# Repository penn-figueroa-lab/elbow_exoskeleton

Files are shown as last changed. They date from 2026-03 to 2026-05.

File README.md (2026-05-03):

# 💪 Elbow Exoskeleton Project (On-Going*)






<div align="center">
<p float="left">
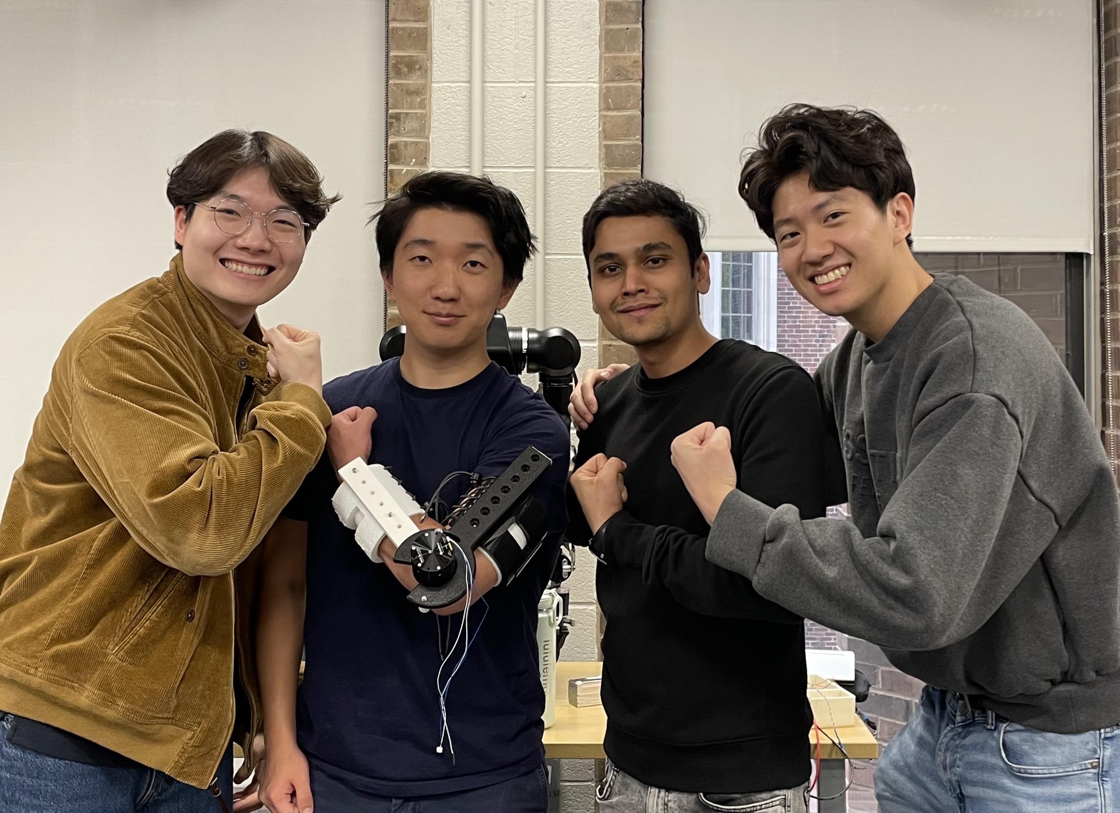
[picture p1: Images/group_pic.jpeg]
Elbow Exoskeleton
  
</p>
</div>

---

## 📋 Table of Contents

- [Overview](#-overview)
- [Key Features](#-key-features)
- [Repository Structure](#-repository-structure)
- [System Architecture](#-system-architecture)
- [Technical Approach](#-technical-approach)
  - [1. Hardware Design](#1-hardware-design)
    - [1.1 Left vs. Right Arm Versions](#11-left-vs-right-arm-versions)
    - [1.2 Structural Linkages](#12-structural-linkages)
    - [1.3 Orthotics](#13-orthotics)
    - [1.4 Safety Systems](#14-safety-systems)
    - [1.5 Snap-Fit Forearm Extension](#15-snap-fit-forearm-extension)
    - [1.6 Materials & Print Settings](#16-materials--print-settings)
    - [1.7 Bill of Materials](#17-bill-of-materials)
  - [2. Multi-Modal Sensor Fusion](#2-multi-modal-sensor-fusion)
  - [3. Comparative Controller Evaluation](#3-comparative-controller-evaluation)
- [CAD Files](#-cad-files)
- [STL Files & Printing Guide](#-stl-files--printing-guide)
- [Assembly Instructions](#-assembly-instructions)
- [Donning & Doffing](#-donning--doffing)
- [Performance Results](#-performance-results)
- [Acknowledgments](#-acknowledgments)

---

## 🎯 Overview

Upper limb exoskeletons for repetitive industrial tasks must adapt to time-varying human dynamics: fatigue, impedance changes, and overlapping kinematics. Single-modality sensing leads to state misclassification and suboptimal assistance. This project develops a sensor fusion framework integrating EMG, IMU, and MoCap to robustly estimate user state during repetitive lifting tasks. Through comparative controller evaluation and ablation studies, we quantify how multi-modal sensing improves adaptive control performance and enables more reliable, responsive assistance.

---

**Institution**: University of Pennsylvania  
**Exoskeleton**: 1-DOF elbow, 0–115° ROM, 1100 g total weight  
**Actuator**: Cubemars AK45-36 KV80 BLDC (15 Nm continuous, 24 Nm peak)  
**Sensing**: EMG + IMU + Motion Capture

---

## ✨ Key Features

### 🔧 Core Capabilities

- ✅ **Single-DOF Elbow Exoskeleton** — 0–115° range of motion, matching typical human elbow flexion/extension
- ✅ **Left & Right Arm Versions** — mirrored CAD designs accommodating both limbs
- ✅ **Cubemars AK45-36 BLDC Actuator** — 15 Nm output torque, back-driven for transparency
- ✅ **Snap-Fit Forearm Linkage** — two-piece print-in-place design compensating for ~8 mm elbow COR shift during actuation
- ✅ **Dual Safety Stops** — software joint-angle limit + hardware M6 screw/nut with TPU cover
- ✅ **Multi-Size Orthotics** — 3 forearm sizes (R35/40/45) and 3 upper arm sizes (R45/50/55 mm inner radius)
- ✅ **Structural Orthotic Inserts** — PLA inserts inside TPU orthotics to minimize torsional twist at linkage interfaces
- ✅ **EMG Sensor Slots** — integrated bicep and tricep sensor pockets in upper arm orthotic
- ✅ **Back-Mounted Power/Control Unit** — 650 g, wireless operation
- ✅ **Multi-Modal Sensor Fusion** — EMG + IMU + MoCap integrated state estimation
- ✅ **Fatigue Detection** — tracks time-varying muscle activation and joint impedance
- ✅ **Comparative Controller Study** — ablation analysis (EMG-only, IMU-only, fused)
- ✅ **Adaptive Assistance** — torque profiles adjust to detected user state

### 🎓 Advanced Techniques

- Kalman filtering for sensor fusion across asynchronous EMG/IMU/MoCap streams
- Fatigue index computation from EMG median frequency shift and RMS amplitude decay
- Impedance estimation from joint torque-angle phase portraits
- Overlapping kinematic disambiguation via multi-modal likelihood weighting

---

## 📁 Repository Structure

```
elbow_exoskeleton/
├── Images/                        # Photos and renders used in README
├── CAD/
│   ├── Elbow Exoskeleton - Left/  # SolidWorks files for the left arm assembly
│   │   ├── Elbow Exoskeleton - Left.sldasm
│   │   ├── Forearm linkage assembly.sldasm
│   │   ├── Forearm linkage base.sldprt
│   │   ├── Forearm linkage front.sldprt
│   │   ├── Forearm orthotic R45 - Left.sldprt
│   │   ├── Forearm orthotic structural insert.sldprt
│   │   ├── Mechanical stop cover.sldprt
│   │   ├── Upper arm linkage - Left.sldprt
│   │   ├── Upper arm orthotic R55 - Left.sldprt
│   │   ├── Upper arm orthotic structural insert.sldprt
│   │   ├── AK45-36-KV80 motor.sldprt
│   │   ├── ANR Muscle Sense Model M40 EMG sensor.sldprt
│   │   ├── 90592A016_Steel Hex Nut_M6.sldprt
│   │   ├── 92005A427_Steel Pan Head Phillips Screw_M6_18mm.sldprt
│   │   └── 92005A435_Steel Pan Head Phillips Screw_M6_30mm.sldprt
│   ├── Elbow Exoskeleton - Right/ # SolidWorks files for the right arm assembly
│   │   ├── Elbow Exoskeleton - Right.sldasm
│   │   ├── Forearm linkage assembly.sldasm
│   │   ├── Forearm linkage base.sldprt
│   │   ├── Forearm linkage front.sldprt
│   │   ├── Forearm orthotic R45 - Right.sldprt
│   │   ├── Forearm orthotic structural insert.sldprt
│   │   ├── Mechanical stop cover.sldprt
│   │   ├── Upper arm linkage - Right.sldprt
│   │   ├── Upper arm orthotic R55 - Right.sldprt
│   │   ├── Upper arm orthotic structural insert.sldprt
│   │   ├── AK45-36-KV80 motor.sldprt
│   │   ├── ANR Muscle Sense Model M40 EMG sensor.sldprt
│   │   ├── 90592A016_Steel Hex Nut_M6.sldprt
│   │   ├── 92005A427_Steel Pan Head Phillips Screw_M6_18mm.sldprt
│   │   └── 92005A435_Steel Pan Head Phillips Screw_M6_30mm.sldprt
│   └── STL files/                 # Print-ready STL files for all printed parts
│       ├── Forearm linkage assembly.stl
│       ├── Forearm orthotic R35/R40/R45 - Left/Right.stl  (6 files)
│       ├── Upper arm orthotic R45/R50/R55 - Left/Right.stl (6 files)
│       ├── Forearm orthotic structural insert.stl
│       ├── Upper arm orthotic structural insert.stl
│       ├── Upper arm linkage - Left/Right.stl
│       └── Mechanical stop cover.stl
├── Print Files/
│   ├── BambuStudio/               # .3mf Bambu Studio project files with pre-configured print settings
│   └── Print Orientation Guide/   # Screenshots showing recommended print orientations
└── README.md
```

> **Note on Left vs. Right folders:** Each assembly folder contains all parts needed to open and rebuild that assembly in SolidWorks — shared parts (forearm linkage, structural inserts, hardware) are duplicated across both folders for self-containment. The only parts that differ between folders are the upper arm linkage, upper arm orthotic, and forearm orthotic, which are mirrored versions of each other. Only **one orthotic size is included per assembly folder** (the example shown uses R45 forearm / R55 upper arm) — select the appropriate size for your subject from the full set in `CAD/STL files/`.

---

## 🏗️ System Architecture

```
┌─────────────────────────────────────────────────────────────────────┐
│              ELBOW EXOSKELETON CONTROL SYSTEM                       │
│                                                                     │
│   ┌──────────────────────────────────────────────────────────────┐  │
│   │                  SENSING LAYER                               │  │
│   │                                                              │  │
│   │   EMG Sensors (biceps, triceps)                              │  │
│   │     ├── Muscle activation intent                             │  │
│   │     └── Fatigue indicators (median freq, RMS)                │  │
│   │                      │                                       │  │
│   │   IMU (elbow joint)                                          │  │
│   │     ├── Joint angle, velocity, acceleration                  │  │
│   │     └── Motion phase detection                               │  │
│   │                      │                                       │  │
│   │   MoCap (ground truth)                                       │  │
│   │     └── High-precision kinematic validation                  │  │
│   └──────────────────────┬───────────────────────────────────────┘  │
│                          │                                          │
│                          ▼                                          │
│   ┌──────────────────────────────────────────────────────────────┐  │
│   │              SENSOR FUSION FRAMEWORK                         │  │
│   │                                                              │  │
│   │   Kalman Filter / Complementary Filter                       │  │
│   │     Input:  EMG(t), IMU(t), MoCap(t)                         │  │
│   │     Output: User state estimate                              │  │
│   │                                                              │  │
│   │   State variables:                                           │  │
│   │     - Joint angle θ, velocity θ̇                              │  │
│   │     - Muscle activation level (normalized EMG)               │  │
│   │     - Fatigue index (0 = fresh, 1 = exhausted)               │  │
│   │     - Estimated joint impedance                              │  │
│   └──────────────────────┬───────────────────────────────────────┘  │
│                          │  fused state estimate                    │
│                          ▼                                          │
│   ┌──────────────────────────────────────────────────────────────┐  │
│   │          COMPARATIVE CONTROLLER EVALUATION                   │  │
│   │                                                              │  │
│   │   Controller A: EMG-only (baseline)                          │  │
│   │   Controller B: IMU-only (baseline)                          │  │
│   │   Controller C: Fused EMG+IMU+MoCap (proposed)               │  │
│   │                                                              │  │
│   │   Metrics: Assistance timing accuracy, torque tracking,      │  │
│   │            false positive rate, fatigue adaptation           │  │
│   └──────────────────────┬───────────────────────────────────────┘  │
│                          │  torque command                          │
│                          ▼                                          │
│   ┌──────────────────────────────────────────────────────────────┐  │
│   │          ADAPTIVE CONTROLLER                                 │  │
│   │                                                              │  │
│   │   Torque profile selection based on:                         │  │
│   │     - Detected motion phase (rest / lift / lower)            │  │
│   │     - Fatigue level (scale assistance magnitude)             │  │
│   │     - Estimated impedance (adjust compliance)                │  │
│   └──────────────────────┬───────────────────────────────────────┘  │
│                          │                                          │
│                          ▼                                          │
│   ┌──────────────────────────────────────────────────────────────┐  │
│   │          CUBEMARS AK45-36 BLDC ACTUATOR                      │  │
│   │                                                              │  │
│   │   Input:   Torque setpoint (Nm)                              │  │
│   │   Output:  Elbow joint torque (15 Nm max continuous)         │  │
│   │   Control: Current loop on motor controller                  │  │
│   └──────────────────────────────────────────────────────────────┘  │
└─────────────────────────────────────────────────────────────────────┘
```

---

## 🔬 Technical Approach

<div align="center">
<p float="left">
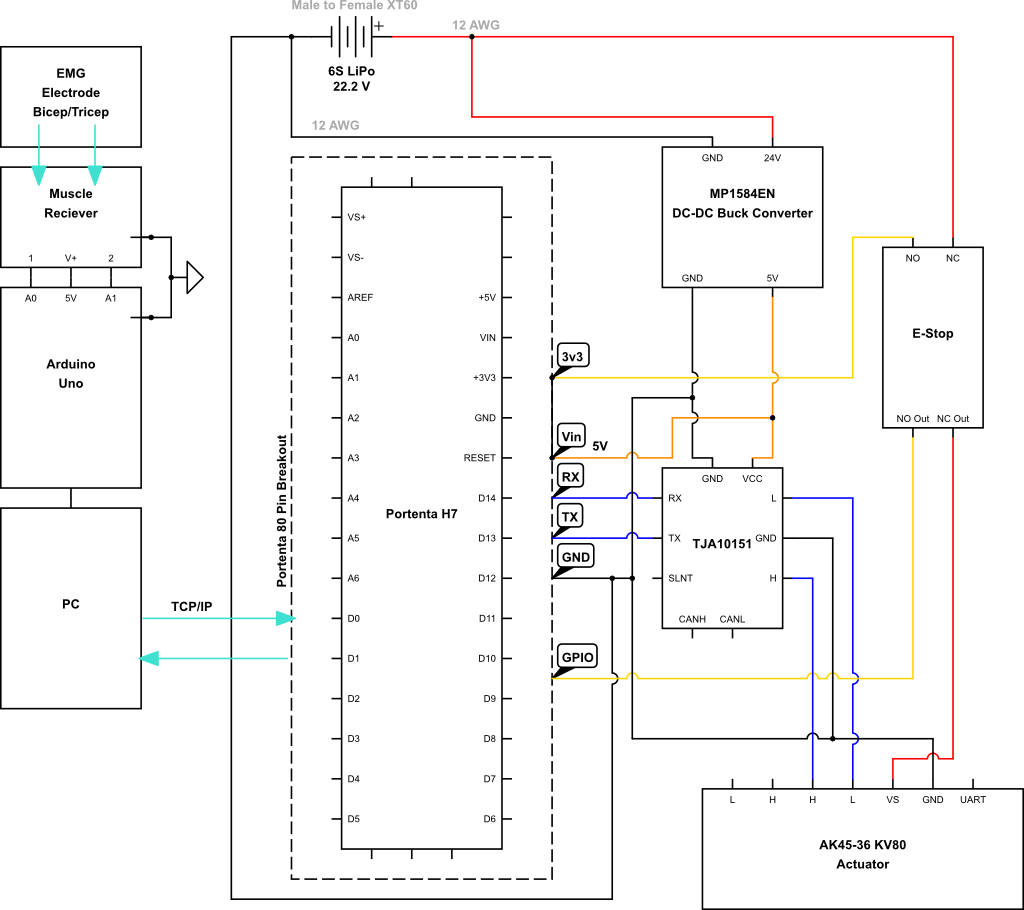
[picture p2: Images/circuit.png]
Electronics circuit
  
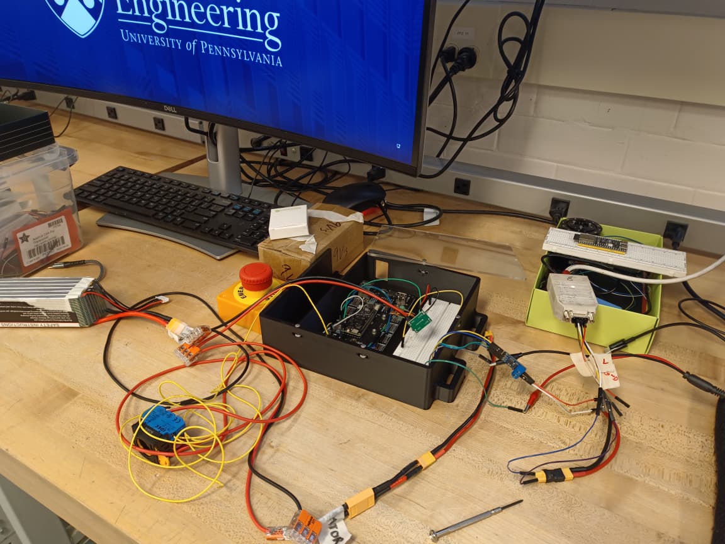
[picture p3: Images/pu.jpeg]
Power unit
  
</p>
</div>

### 1. Hardware Design

#### 1.1 Left vs. Right Arm Versions

The exoskeleton is available in two mirrored versions — **Left** and **Right** — to accommodate both arms. The motor is positioned at the elbow joint and the user operates with **palms facing upward** (supinated). Shoe laces run along the **top** of each orthotic, and the orthotics mount to their respective linkages from the side.

The **forearm linkage assembly is identical** across both versions. Only the following parts differ (mirrored CAD):

| Part | Left Version | Right Version |
|---|---|---|
| Upper arm linkage | ✅ | ✅ |
| Upper arm orthotic | ✅ | ✅ |
| Forearm orthotic | ✅ | ✅ |
| Forearm linkage | Shared | Shared |

<div align="center">
<p float="left">
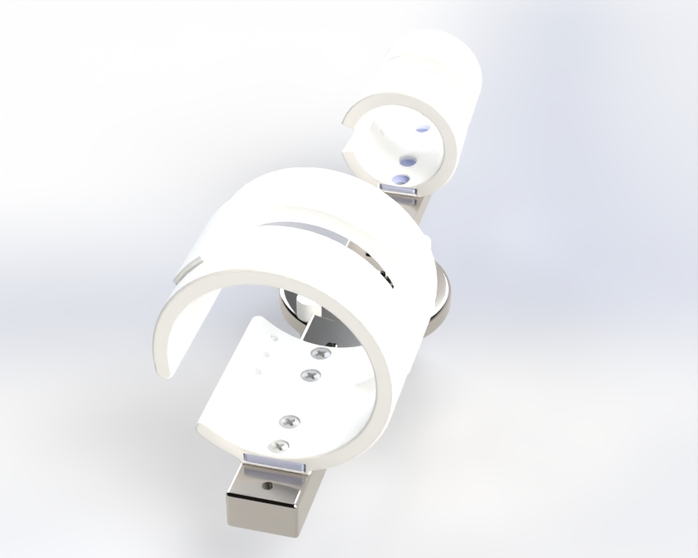
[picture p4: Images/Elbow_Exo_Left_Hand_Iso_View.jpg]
Left arm version
  
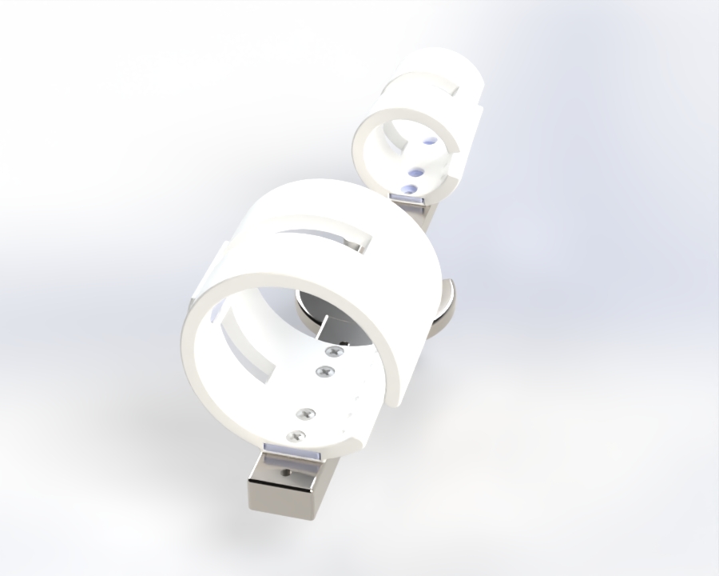
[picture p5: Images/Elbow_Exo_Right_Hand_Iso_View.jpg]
Right arm version
  
</p>
<em>Left (left) and Right (right) arm versions of the elbow exoskeleton assembly</em>
</div>

#### 1.2 Structural Linkages

<div align="center">
<p float="left">
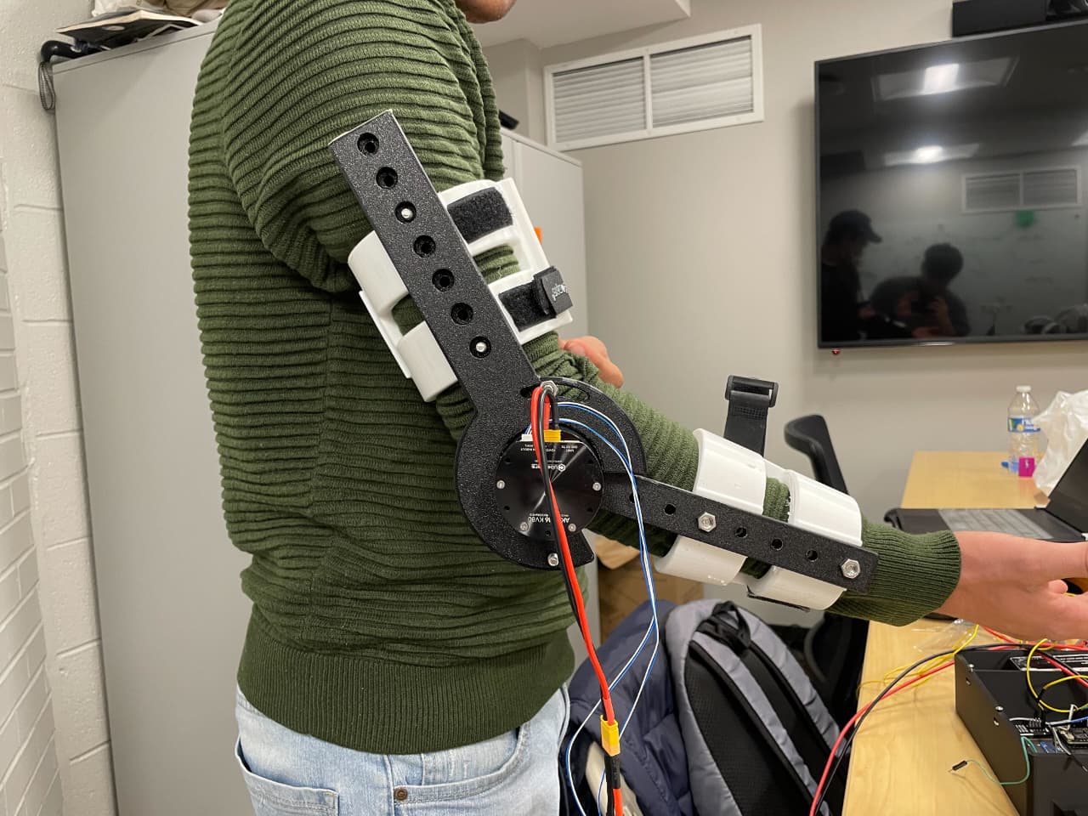
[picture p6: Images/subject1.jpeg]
Exoskeleton on subject
  
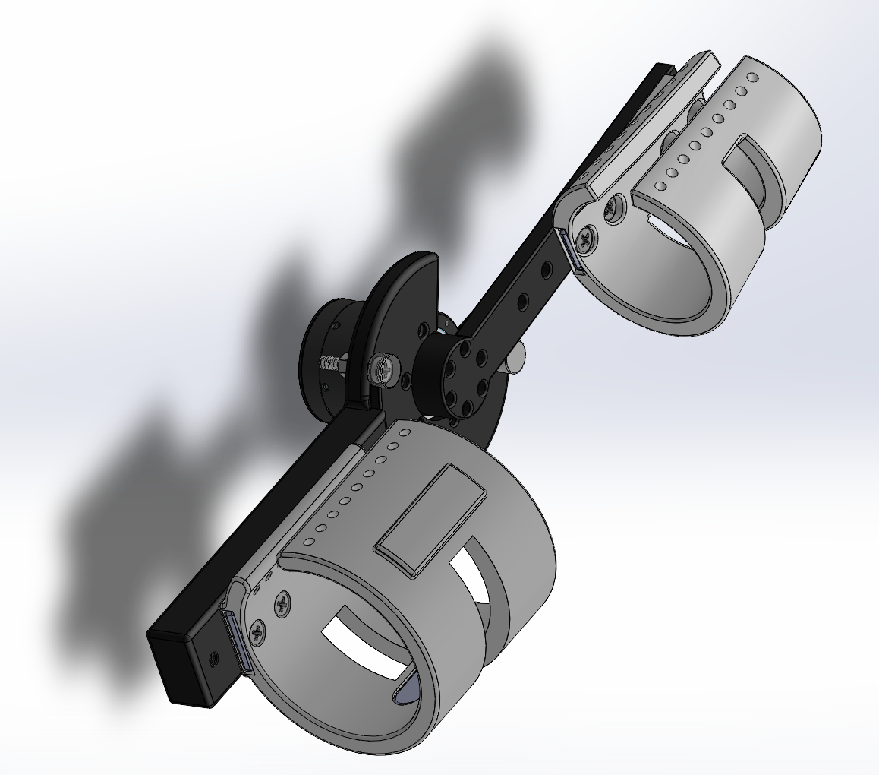
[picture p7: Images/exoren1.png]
Exoskeleton render
  
</p>
</div>

Both linkages bolt directly onto the **Cubemars AK45-36 motor** using M3 screws.

| Component | Dimensions (L × W × H) | Notes |
|---|---|---|
| Forearm linkage | ~210 × 35 × 19 mm | Two-piece snap-fit assembly |
| Upper arm linkage | ~270 × 110 × 24 mm | Left/right mirrored versions |

Each linkage features **6–7 orthotic mounting holes spaced 21 mm apart**, allowing adjustment for different user arm lengths and optimal orthotic placement. The 21 mm hole spacing provides approximately 126 mm of total adjustment range, accommodating a broad range of adult arm proportions.

The wall thicknesses and cross-sections were sized to safely transmit the actuator's 15 Nm continuous output torque, providing adequate safety margin for the expected bending and torsional loads on the linkages.

#### 1.3 Orthotics

Both orthotics are printed in **TPU** for compliance and comfort against the user's skin. Key design features:

- **6 shoe lace holes per side** of the opening for secure tightening onto the user's arm
- **6 mm EVA foam** bonded to the inner surface with Barge cement for pressure distribution and comfort
- **Structural inserts** (printed in PLA, 75% infill) embedded at the orthotic-to-linkage interface to resist torsional twist during actuation
- **3 size options per orthotic** to accommodate different arm circumferences

| Orthotic | Inner Radius Options | Shape | Thickness |
|---|---|---|---|
| Forearm orthotic | R35 / R40 / R45 mm | Slightly tapered (follows human forearm geometry) | 10 mm |
| Upper arm orthotic | R45 / R50 / R55 mm | Cylindrical | 10 mm |

The 10 mm wall thickness balances structural rigidity with mass, limiting deformation under circumferential loads while remaining flexible enough for comfortable donning/doffing. The R35–R45 forearm range and R45–R55 upper arm range cover a broad range of adult arm circumferences.

The **upper arm orthotic** additionally includes **2 recessed EMG sensor slots** — one positioned over the biceps and one over the triceps — to securely house the ANR Muscle Sense M40 sensors during data collection.

<div align="center">
<p float="left">
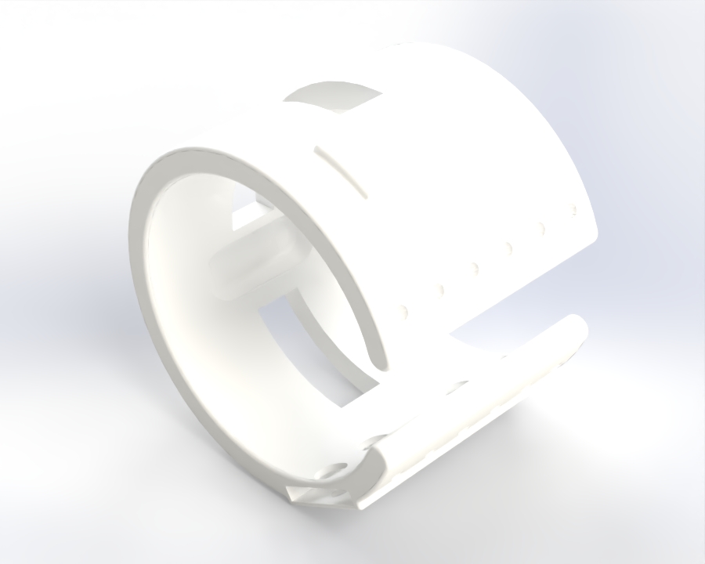
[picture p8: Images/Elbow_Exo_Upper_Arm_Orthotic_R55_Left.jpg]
Upper arm orthotic with EMG slots
  
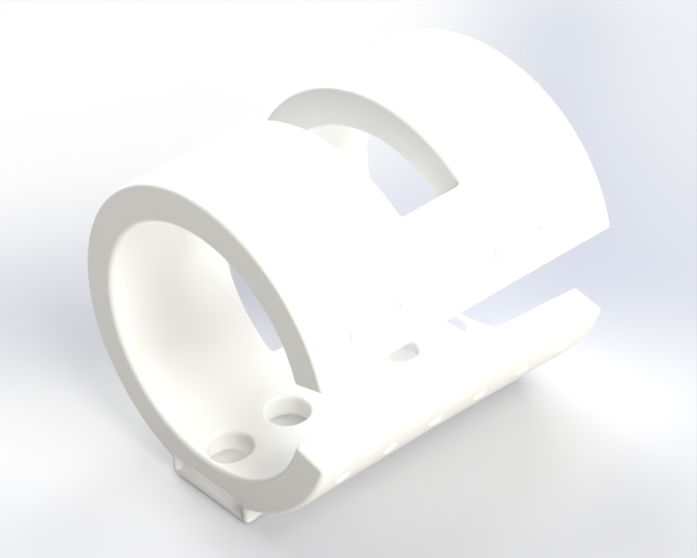
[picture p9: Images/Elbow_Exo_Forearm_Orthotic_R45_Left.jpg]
Forearm orthotic
  
</p>
<em>Upper arm orthotic (left) showing EMG sensor slots and shoe lace holes; Forearm orthotic (right) showing tapered geometry and lace holes</em>
</div>

#### 1.4 Safety Systems

The exoskeleton incorporates **two independent layers of safety** to protect the user from joint over-travel:

1. **Software stop**: Joint angle limits enforced in the motor controller firmware (0° and 115°).
2. **Hardware mechanical stop**: Two **M6 screw + M6 hex nut** assemblies physically block the forearm linkage at each end of the range of motion, with a **TPU mechanical stop cover** over each screw head to cushion contact and prevent metal-on-metal impact.

The two hardware stops differ intentionally in their mounting geometry on the upper arm linkage:

- **0° stop (full extension)**: Mounted in a **fixed hole**, providing a firm absolute limit at full extension.
- **115° stop (full flexion)**: Mounted in a **slot** rather than a fixed hole, allowing the screw position to be adjusted by up to ~25°. This accommodates users whose natural maximum elbow flexion differs from the default 115° setting — the effective hardware limit can be set anywhere in the **115°–140°** range to match the individual user's anatomy.

This dual-layer approach ensures that even in the event of a software fault, the user is protected from harmful range-of-motion exceedance.

#### 1.5 Snap-Fit Forearm Extension

During elbow flexion/extension, the **center of rotation (COR) of the human elbow joint shifts by approximately 8 mm** due to the cam-like geometry of the distal humerus. A rigid forearm linkage would fight this shift, creating uncomfortable shear forces on the user's arm.

To compensate, the forearm linkage is split into two pieces — a **base** and a **front** — joined by a **print-in-place snap-fit**. This allows the linkage to extend longitudinally, passively accommodating the COR shift throughout the range of motion without requiring any user adjustment.

<div align="center">
<p float="left">
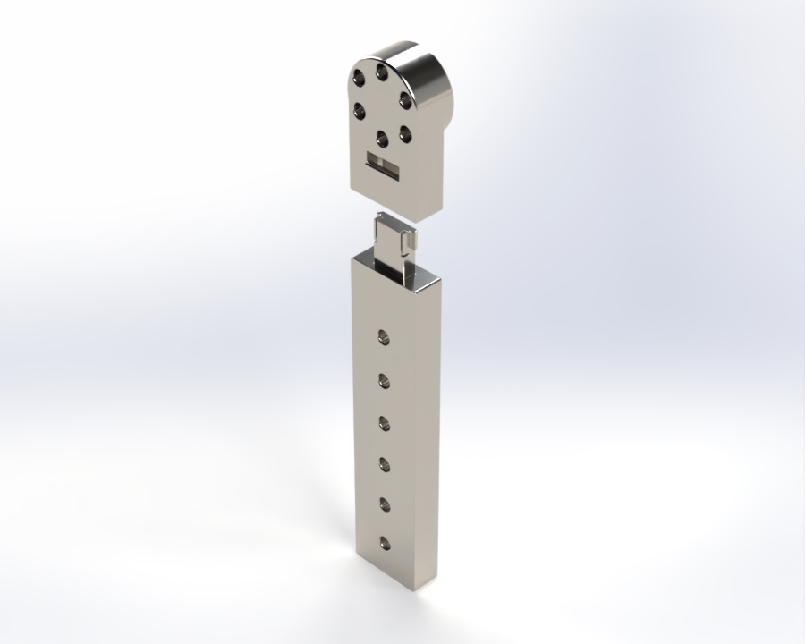
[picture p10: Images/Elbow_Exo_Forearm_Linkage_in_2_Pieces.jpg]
Snap-fit two separate pieces
  
</p>
<em>The two pieces of the forearm linkage — base (bottom) and front (top) — before assembly</em>
</div>

<div align="center">
<p float="left">
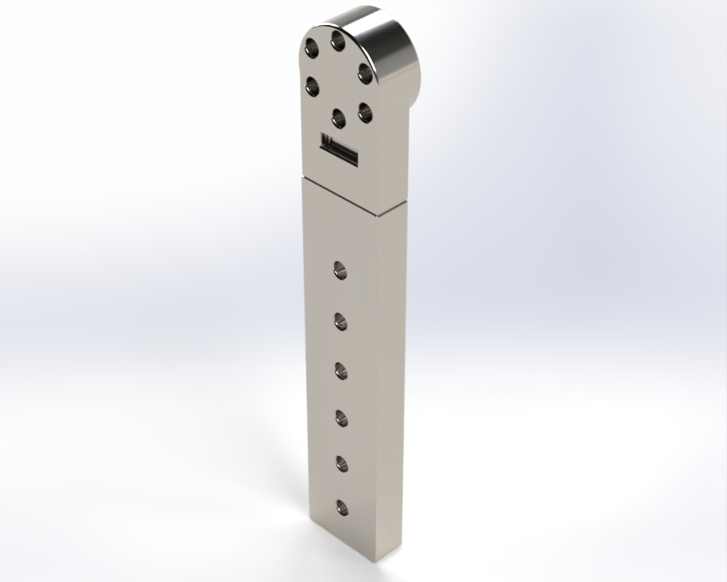
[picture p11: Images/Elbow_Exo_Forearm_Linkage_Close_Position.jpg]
Snap-fit closed/retracted position
  
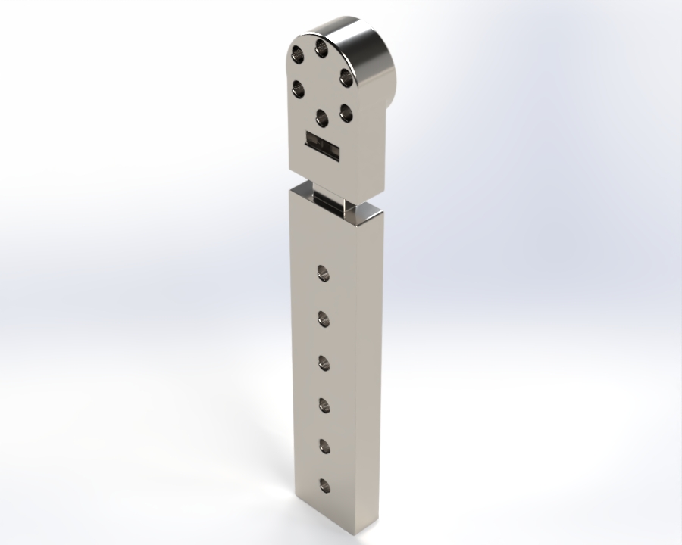
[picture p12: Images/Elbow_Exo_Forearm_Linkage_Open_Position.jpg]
Snap-fit open/extended position
  
</p>
<em>Snap-fit forearm linkage in retracted position (left) and extended position (right), passively accommodating the ~8 mm elbow COR shift during actuation</em>
</div>

#### 1.6 Materials & Print Settings

All parts use **4 perimeter wall loops**, which is the primary driver of strength in FDM prints — particularly for thin-walled curved geometries like orthotics where the walls *are* the structure.

| Part | Material | Infill | Wall Loops | Rationale |
|---|---|---|---|---|
| Forearm linkage (base + front) | PLA | 75% | 4 | Structural; transmits motor torque |
| Upper arm linkage (L/R) | PLA | 75% | 4 | Structural; transmits motor torque |
| Forearm orthotic structural insert | PLA | 75% | 4 | Stiffens orthotic-linkage interface |
| Upper arm orthotic structural insert | PLA | 75% | 4 | Stiffens orthotic-linkage interface |
| Forearm orthotics (all sizes, L/R) | TPU | 15% | 4 | Flexible and compliant; walls provide shape, low infill keeps part soft and lightweight |
| Upper arm orthotics (all sizes, L/R) | TPU | 15% | 4 | Flexible and compliant; walls provide shape, low infill keeps part soft and lightweight |
| Mechanical stop cover | TPU | 15% | 4 | Soft impact absorption; low infill maximises cushioning effect |

**PLA parts (75% infill):** 75% infill provides near-maximum mechanical performance for structural components. Diminishing returns in tensile strength occur beyond ~70–80% infill, making 75% a practical ceiling for load-bearing parts.

**TPU parts (15% infill):** For flexible TPU orthotics and the mechanical stop cover, low infill (15%) is intentional — it preserves the material's compliance and keeps mass low, while the 4 wall loops provide sufficient shape retention and contact stiffness at the skin interface. Higher infill in TPU would make the part unnecessarily stiff and heavy without meaningful structural benefit.

**Print orientation notes**: See `Print Files/Print Orientation Guide/` for Bambu Studio screenshots. Key considerations:
- **Orthotics**: Print standing upright with the opening face-down to maximize layer adhesion around the circumference and shoe lace holes.
- **Forearm linkage assembly**: Print flat with the snap-fit joint oriented horizontally to ensure proper engagement of the snap features.
- **Linkages**: Print flat on their largest face to maximize bending strength along the primary load direction.

#### 1.7 Bill of Materials

| Item | Quantity | Notes |
|---|---|---|
| Cubemars AK45-36 KV80 BLDC motor | 1 | Actuator, 15 Nm continuous |
| ANR Muscle Sense M40 EMG sensor | 2 | Bicep + tricep |
| M3 screws (motor mount) | ~8 | Linkage-to-motor attachment |
| M6 × 18 mm Pan Head Phillips screw | 2 | Hardware stop (0° and 115°) |
| M6 × 30 mm Pan Head Phillips screw | As needed | Hardware stop alternate length |
| M6 hex nut | 2 | Hardware stop |
| PLA filament | ~500 g | Linkages and structural inserts |
| TPU filament | ~300 g | Orthotics and mechanical stop cover |
| 6 mm EVA foam sheet | ~400 cm² | Inner orthotic padding |
| Barge contact cement | Small amount | Bonding EVA foam to orthotics |
| Shoe laces | 2 pairs | Securing orthotics to user |

---

## 🔩 Assembly Instructions

### Part 1 — Print & Hardware Prep

1. Print all 3D printed parts using the provided `.3mf` files (see [STL Files & Printing Guide](#-stl-files--printing-guide)). Remove all supports after printing — note that TPU support removal is particularly time-consuming.
2. Gather all hardware: M3 screws, M6 screws, M6 hex nuts, and mechanical stop covers.

### Part 2 — EVA Foam Padding

3. Cut the 6 mm EVA foam sheets to the approximate shape of the inner surface of each orthotic.
4. Apply Barge contact cement to both the EVA foam and the inner surface of the orthotic. Allow to become tacky per the cement's instructions, then press the foam firmly onto the orthotic interior.
5. Trim any excess foam with scissors so it sits flush with the orthotic edges.
6. Place a cylindrical object (e.g. a water bottle or PVC pipe of similar diameter) inside each orthotic to apply constant outward pressure on the foam against the orthotic wall while the cement fully cures. Leave until fully adhered.

### Part 3 — Orthotic Assembly

7. Thread shoe laces through the 6 lace holes on each side of both orthotics.
8. Screw each orthotic to its respective linkage using the orthotic mounting holes. Select the mounting hole position that best matches the user's arm length for optimal coverage and comfort.
9. Press the PLA structural inserts into the orthotic-to-linkage interface locations to reinforce those areas against torsional twist during actuation.

### Part 4 — Linkage-to-Motor Assembly

10. Attach the forearm linkage assembly to the Cubemars AK45-36 motor output shaft using M3 screws.
11. Attach the upper arm linkage to the motor body using M3 screws.
12. Install the two M6 hardware stops: the fixed-hole stop for the 0° (full extension) limit and the slot-mounted stop for the 115°–140° (full flexion) limit. Fit the TPU mechanical stop covers over each screw head.

---

## 🦾 Donning & Doffing

The exoskeleton is worn and removed as a **single fully-assembled unit** — the linkages, orthotics, and motor are not disassembled between uses. Donning and doffing simply involves sliding the assembled system onto or off the arm.

### Putting On

1. Loosen the shoe laces on both orthotics fully.
2. With the arm **straight out** (fully extended, 0°), slide the assembled exoskeleton onto the arm — the **upper arm orthotic end goes on first**, positioning it along the upper arm.
3. Continue sliding the assembly along the arm until the **forearm orthotic sits along the forearm** and, critically, the **motor sits at the elbow joint center of rotation**. This alignment is essential for comfort and effective torque transmission.
4. Tighten the shoe laces on both orthotics until they are secure but not uncomfortable for the user.
5. Connect the electronics and power source. The exoskeleton is ready to operate.

### Taking Off

1. Power down and disconnect the electronics and power source.
2. Loosen the shoe laces on both orthotics.
3. Slide the entire assembled exoskeleton off the arm, **forearm end first**.

---

## 📐 CAD Files

The SolidWorks files are organised into two self-contained assembly folders under `CAD/` — one per arm side — each containing all parts needed to open and fully resolve the assembly.

**[`CAD/Elbow Exoskeleton - Left/`](CAD/Elbow%20Exoskeleton%20-%20Left/)**
- `Elbow Exoskeleton - Left.sldasm`
- `Forearm linkage assembly.sldasm`, `Forearm linkage base.sldprt`, `Forearm linkage front.sldprt`
- `Upper arm linkage - Left.sldprt`
- `Forearm orthotic R45 - Left.sldprt`, `Forearm orthotic structural insert.sldprt`
- `Upper arm orthotic R55 - Left.sldprt`, `Upper arm orthotic structural insert.sldprt`
- `Mechanical stop cover.sldprt`
- `AK45-36-KV80 motor.sldprt`, `ANR Muscle Sense Model M40 EMG sensor.sldprt`
- `90592A016_Steel Hex Nut_M6.sldprt`, `92005A427_Steel Pan Head Phillips Screw_M6_18mm.sldprt`, `92005A435_Steel Pan Head Phillips Screw_M6_30mm.sldprt`

**[`CAD/Elbow Exoskeleton - Right/`](CAD/Elbow%20Exoskeleton%20-%20Right/)** *(identical structure, right-side mirrored parts)*
- `Elbow Exoskeleton - Right.sldasm`
- Same shared parts as above
- `Upper arm linkage - Right.sldprt`
- `Forearm orthotic R45 - Right.sldprt`
- `Upper arm orthotic R55 - Right.sldprt`

> Each assembly folder includes only one orthotic size for the assembly reference model. All sizes (R35/R40/R45 forearm; R45/R50/R55 upper arm) are available as STL files in [`CAD/STL files/`](CAD/STL%20files/) for printing.

---

## 🖨️ STL Files & Printing Guide

All print-ready STL files are in [`CAD/STL files/`](CAD/STL%20files/). Print settings for each part are listed below. For recommended print orientations and bed setups for each part, see the **[Print Guide](Print%20Files/Print%20Orientation%20Guide/PRINT_ORIENTATION_GUIDE.md)**. The Bambu Studio `.3mf` files below are configured for the **Bambu Lab P1S**.

| File | Material | Infill | Wall Loops |
|---|---|---|---|
| [Forearm linkage assembly](CAD/STL%20files/Forearm%20linkage%20assembly.STL) | PLA | 75% | 4 |
| [Upper arm linkage - Left](CAD/STL%20files/Upper%20arm%20linkage%20-%20Left.STL) | PLA | 75% | 4 |
| [Upper arm linkage - Right](CAD/STL%20files/Upper%20arm%20linkage%20-%20Right.STL) | PLA | 75% | 4 |
| [Forearm orthotic R35 - Left](CAD/STL%20files/Forearm%20orthotic%20R35%20-%20Left.STL) | TPU | 15% | 4 |
| [Forearm orthotic R35 - Right](CAD/STL%20files/Forearm%20orthotic%20R35%20-%20Right.STL) | TPU | 15% | 4 |
| [Forearm orthotic R40 - Left](CAD/STL%20files/Forearm%20orthotic%20R40%20-%20Left.STL) | TPU | 15% | 4 |
| [Forearm orthotic R40 - Right](CAD/STL%20files/Forearm%20orthotic%20R40%20-%20Right.STL) | TPU | 15% | 4 |
| [Forearm orthotic R45 - Left](CAD/STL%20files/Forearm%20orthotic%20R45%20-%20Left.STL) | TPU | 15% | 4 |
| [Forearm orthotic R45 - Right](CAD/STL%20files/Forearm%20orthotic%20R45%20-%20Right.STL) | TPU | 15% | 4 |
| [Upper arm orthotic R45 - Left](CAD/STL%20files/Upper%20arm%20orthotic%20R45%20-%20Left.STL) | TPU | 15% | 4 |
| [Upper arm orthotic R45 - Right](CAD/STL%20files/Upper%20arm%20orthotic%20R45%20-%20Right.STL) | TPU | 15% | 4 |
| [Upper arm orthotic R50 - Left](CAD/STL%20files/Upper%20arm%20orthotic%20R50%20-%20Left.STL) | TPU | 15% | 4 |
| [Upper arm orthotic R50 - Right](CAD/STL%20files/Upper%20arm%20orthotic%20R50%20-%20Right.STL) | TPU | 15% | 4 |
| [Upper arm orthotic R55 - Left](CAD/STL%20files/Upper%20arm%20orthotic%20R55%20-%20Left.STL) | TPU | 15% | 4 |
| [Upper arm orthotic R55 - Right](CAD/STL%20files/Upper%20arm%20orthotic%20R55%20-%20Right.STL) | TPU | 15% | 4 |
| [Forearm orthotic structural insert](CAD/STL%20files/Forearm%20orthotic%20structural%20insert.STL) | PLA | 75% | 4 |
| [Upper arm orthotic structural insert](CAD/STL%20files/Upper%20arm%20orthotic%20structural%20insert.STL) | PLA | 75% | 4 |
| [Mechanical stop cover](CAD/STL%20files/Mechancial%20stop%20cover.STL) | TPU | 15% | 4 |

**Bambu Studio `.3mf` files** (pre-configured for Bambu Lab P1S, located in `Print Files/BambuStudio/`):

| .3mf File | Contents | Material |
|---|---|---|
| `Elbow_Exoskeleton_Left_Linkage_&_Inserts_Prints.3mf` | Forearm linkage assembly + Upper arm linkage Left + both structural inserts | PLA |
| `Elbow_Exoskeleton_Left_Orthotics_&_Mechanical_Stop.3mf` | Forearm orthotic R35 Left + Upper arm orthotic R45 Left + Mechanical stop cover ×2 | TPU |
| `Elbow_Exoskeleton_Right_Linkage_&_Inserts_Prints.3mf` | Forearm linkage assembly + Upper arm linkage Right + both structural inserts | PLA |
| `Elbow_Exoskeleton_Right_Orthotics_&_Mechanical_Stop.3mf` | Forearm orthotic R35 Right + Upper arm orthotic R45 Right + Mechanical stop cover ×2 | TPU |

---

## 📊 Performance Results

### Ablation Study

*On-going*

---

## 📄 Acknowledgments

Research project developed at the **University of Pennsylvania GRASP Lab** under the supervision of **Dr. Nadia Figueroa**.

---

<div align="center">

### 💪 Multi-Modal Sensing for Adaptive Exoskeleton Control

**EMG + IMU + MoCap → Sensor Fusion → User State → Adaptive Control → Elbow Assistance**

---

[⬆ Back to Top](#-elbow-exoskeleton-project-on-going)

</div>

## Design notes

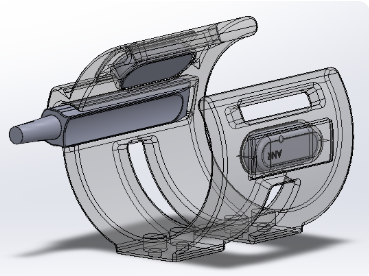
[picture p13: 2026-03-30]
Images/exoren3.png

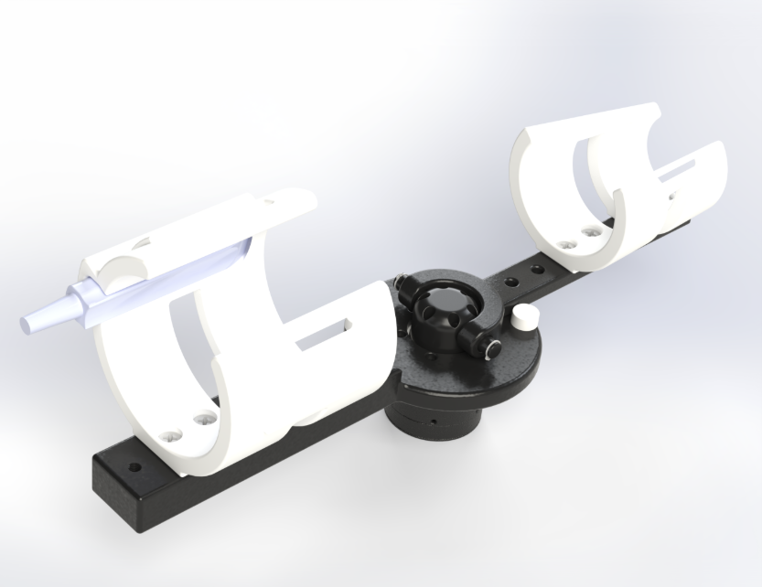
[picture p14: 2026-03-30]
Images/exoren2.png

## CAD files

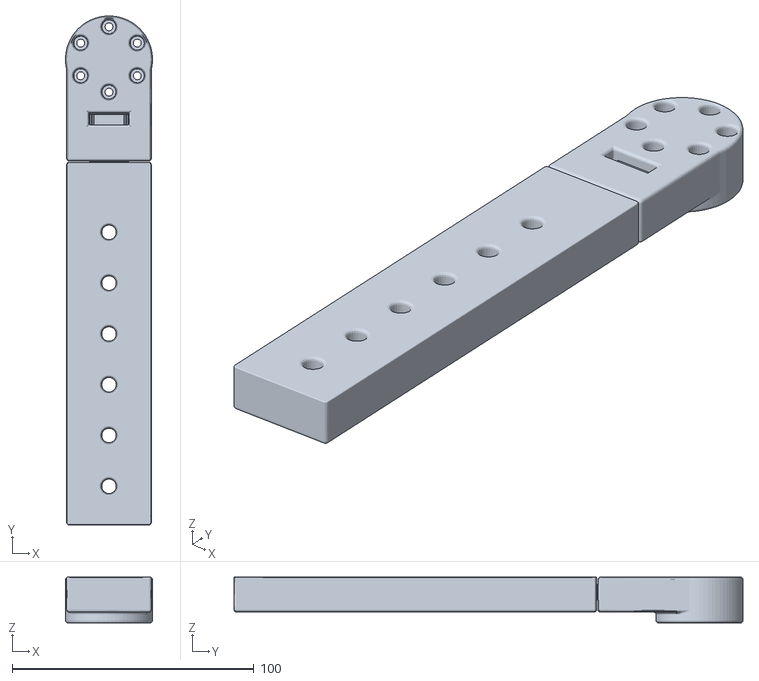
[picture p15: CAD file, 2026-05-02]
CAD/STL files/Forearm linkage assembly.STL
36.0 x 210.5 x 19.0

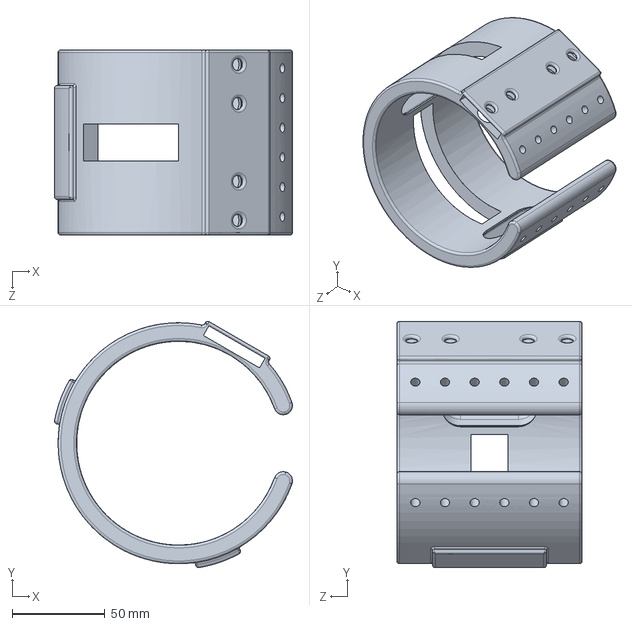
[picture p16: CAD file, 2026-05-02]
CAD/Elbow Exoskeleton - Right/Upper arm orthotic R55 - Right.SLDPRT
128.4 x 132.9 x 100.0 mm

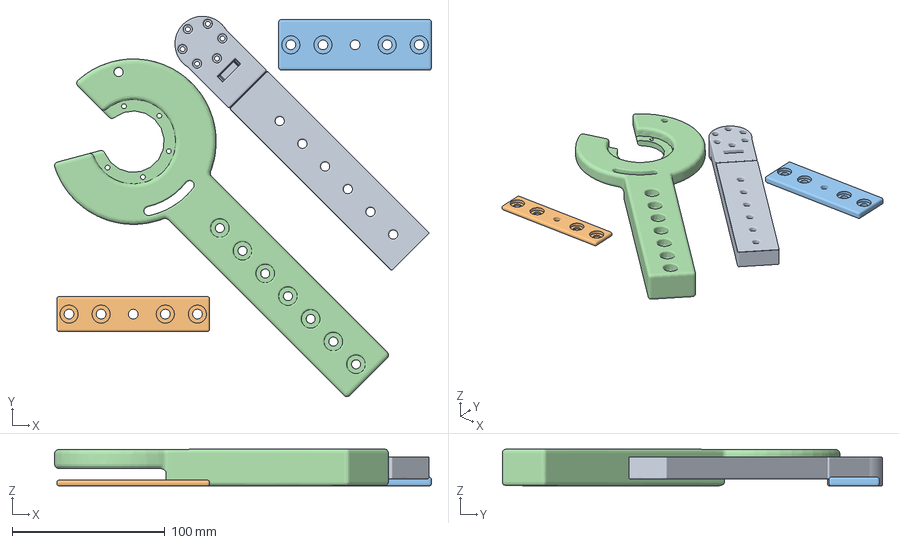
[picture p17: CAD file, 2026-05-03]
Print Files/BambuStudio/Elbow_Exoskeleton_Right_Linkage_&_Inserts_Prints.3mf
246.6 x 248.8 x 24.1 mm
Forearm linkage assembly.STL
Forearm orthotic structural insert.STL
Upper arm orthotic structural insert.STL
Upper arm linkage - Right.STL

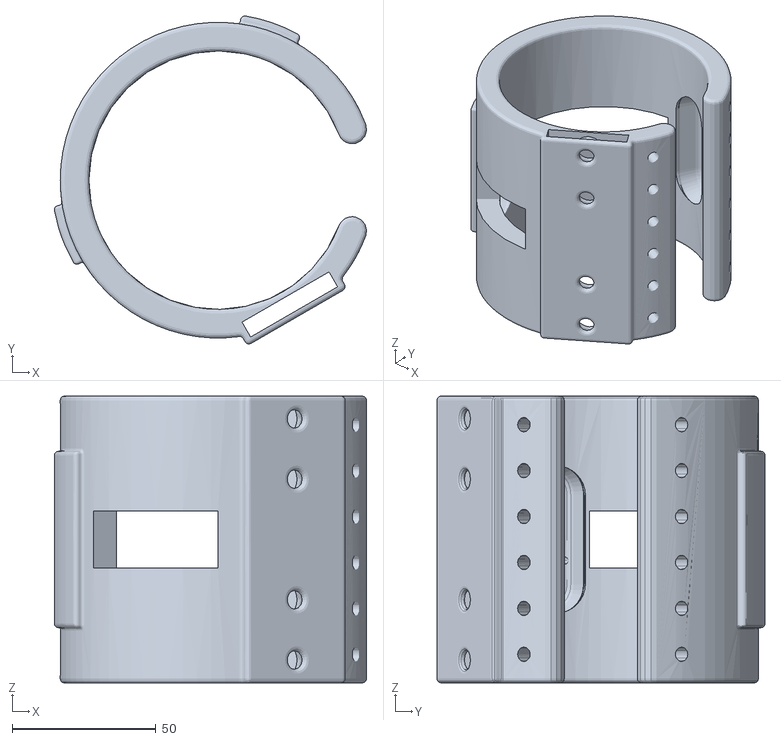
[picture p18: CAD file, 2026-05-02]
CAD/STL files/Upper arm orthotic R45 - Left.STL
108.8 x 114.3 x 100.0

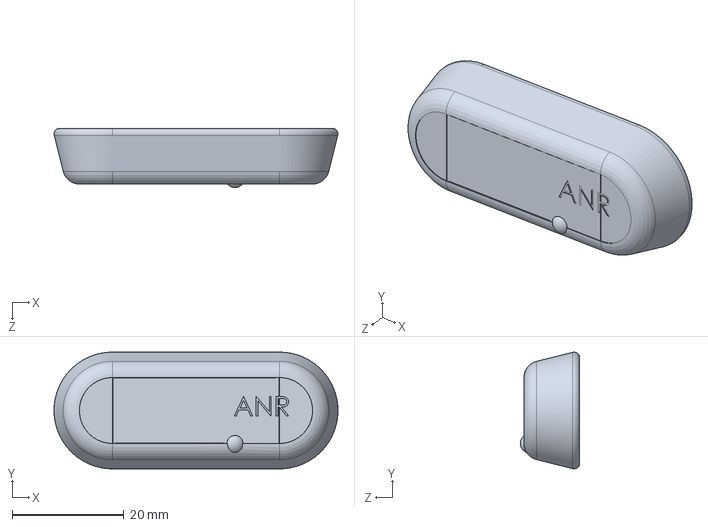
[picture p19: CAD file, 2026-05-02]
CAD/Elbow Exoskeleton - Left/ANR Muscle Sense Model M40 EMG sensor.SLDPRT
50.9 x 20.9 x 10.6 mm

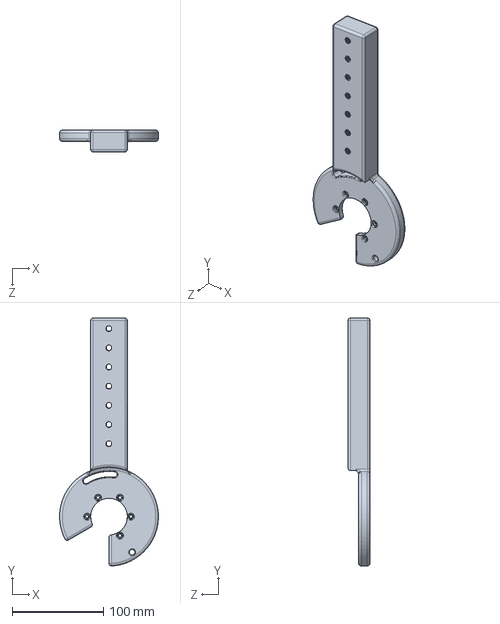
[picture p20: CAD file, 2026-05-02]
CAD/Elbow Exoskeleton - Right/Upper arm linkage - Right.SLDPRT
108.2 x 271.6 x 24.0 mm

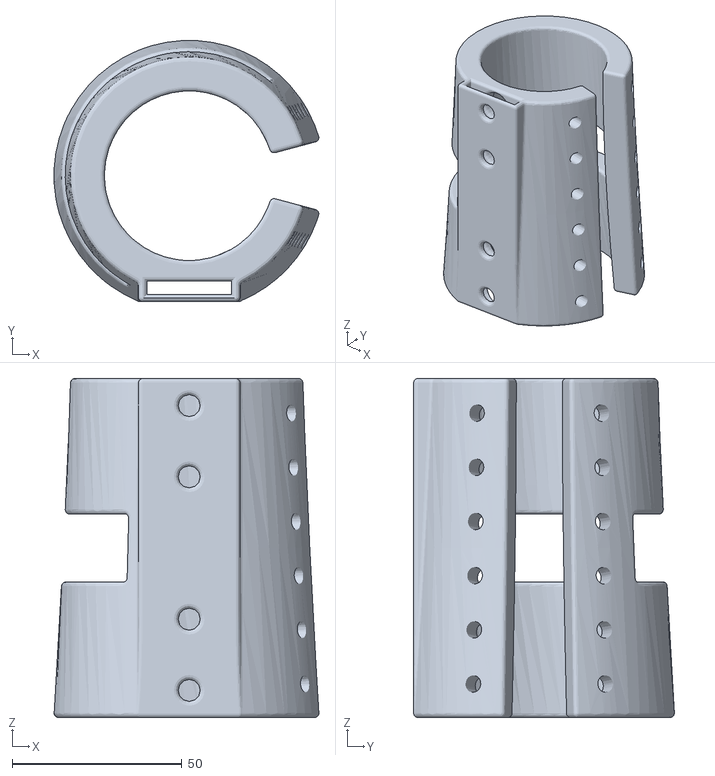
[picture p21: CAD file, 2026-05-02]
CAD/STL files/Forearm orthotic R35 - Left.STL
78.1 x 76.9 x 100.0

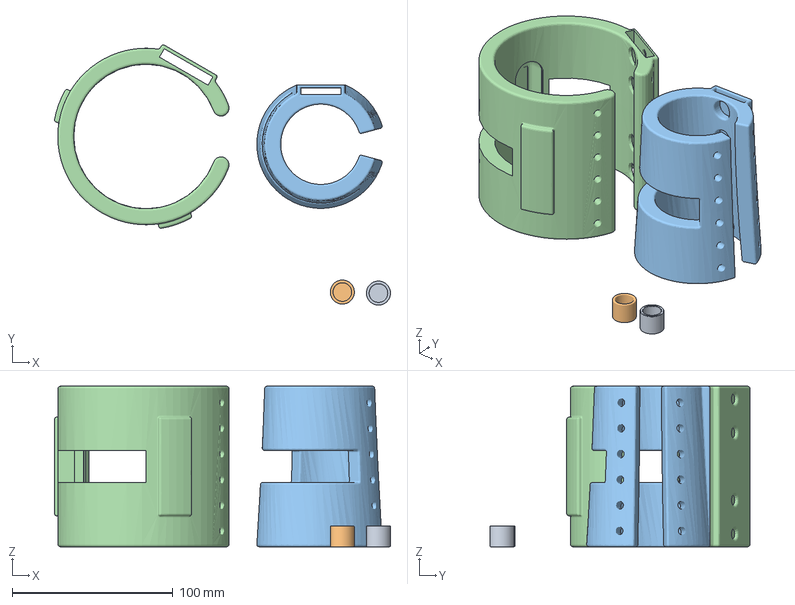
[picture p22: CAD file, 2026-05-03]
Print Files/BambuStudio/Elbow_Exoskeleton_Right_Orthotics_&_Mechanical_Stop.3mf
209.3 x 162.1 x 100.0 mm
Mechancial stop cover.STL x 2
Forearm orthotic R35 - Right.STL
Upper arm orthotic R45 - Right.STL

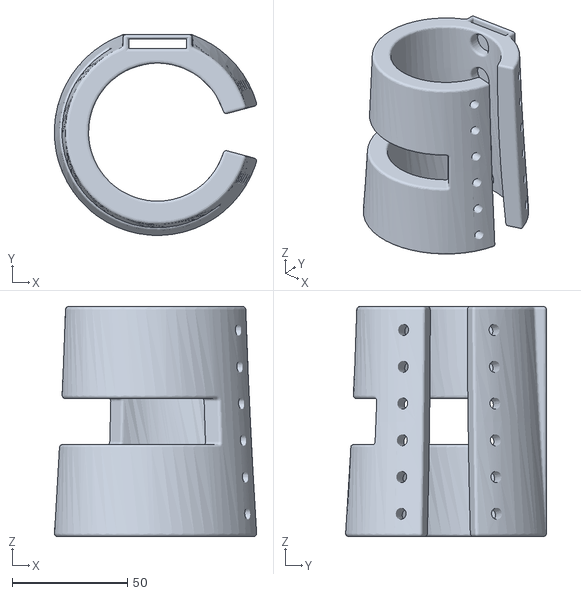
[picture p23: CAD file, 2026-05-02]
CAD/STL files/Forearm orthotic R40 - Right.STL
88.0 x 87.3 x 100.0

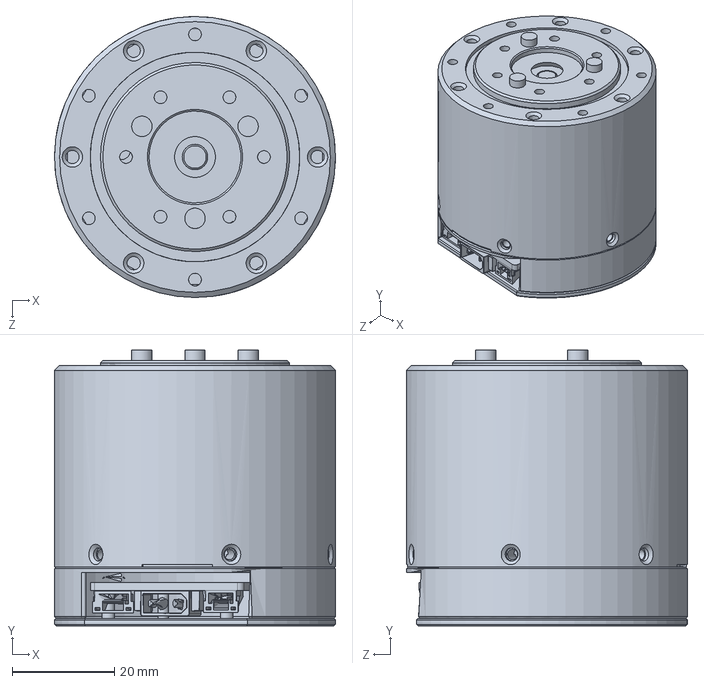
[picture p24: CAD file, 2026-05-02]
CAD/Elbow Exoskeleton - Right/AK45-36-KV80 motor.SLDPRT
55.0 x 54.0 x 55.0 mm

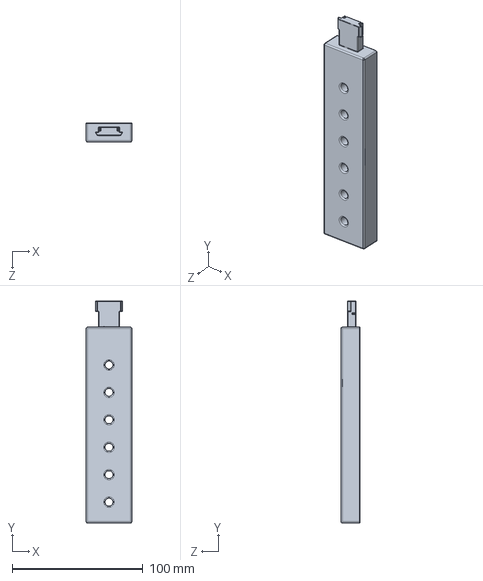
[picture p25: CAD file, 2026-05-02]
CAD/Elbow Exoskeleton - Right/Forearm linkage front.SLDPRT
35.0 x 170.0 x 14.5 mm

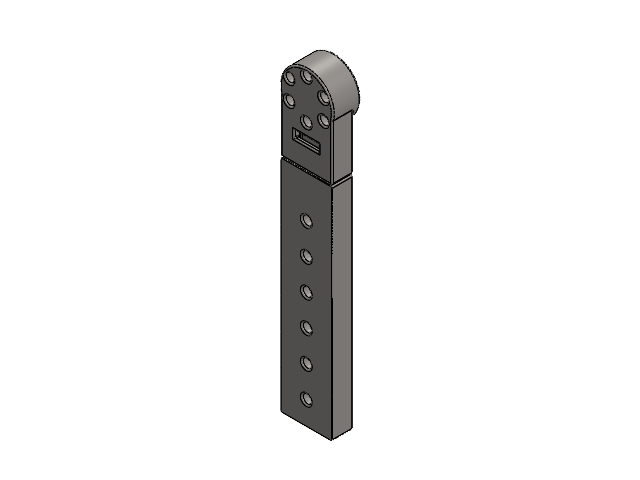
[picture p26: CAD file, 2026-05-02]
CAD/Elbow Exoskeleton - Left/Forearm linkage assembly.SLDASM
Forearm linkage base
Forearm linkage front

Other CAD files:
CAD/Elbow Exoskeleton - Right/Forearm linkage assembly.SLDASM
Print Files/BambuStudio/Elbow_Exoskeleton_Left_Linkage_&_Inserts_Prints.3mf
CAD/Elbow Exoskeleton - Right/Forearm orthotic R35 - Right.SLDPRT
Print Files/BambuStudio/Elbow_Exoskeleton_Left_Orthotics_&_Mechanical_Stop.3mf
CAD/STL files/Forearm orthotic R35 - Right.STL
CAD/Elbow Exoskeleton - Left/Upper arm linkage - Left.SLDPRT
CAD/Elbow Exoskeleton - Left/90592A016_Steel Hex Nut_M6.SLDPRT
CAD/Elbow Exoskeleton - Left/92005A427_Steel Pan Head Phillips Screw_M6_18mm.SLDPRT
CAD/Elbow Exoskeleton - Left/92005A435_Steel Pan Head Phillips Screw_M6_30mm.SLDPRT
CAD/Elbow Exoskeleton - Left/Forearm linkage base.SLDPRT
CAD/Elbow Exoskeleton - Left/Forearm orthotic R35 - Left.SLDPRT
CAD/Elbow Exoskeleton - Left/Forearm orthotic structural insert.SLDPRT
CAD/Elbow Exoskeleton - Left/Mechancial stop cover.SLDPRT
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

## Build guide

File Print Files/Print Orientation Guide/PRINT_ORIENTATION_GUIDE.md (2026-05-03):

# 🖨️ Print Guide — Elbow Exoskeleton

This guide covers the print setup for all printed parts of the elbow exoskeleton. All Bambu Studio `.3mf` project files are configured for the **Bambu Lab P1S** and are available in `Print Files/BambuStudio/`. It is recommended to view prints in **Line Type** color scheme in Bambu Studio to visualize support structures vs. actual print filament before printing.

---

## Print Settings Summary

| Part | Material | Infill | Wall Loops |
|---|---|---|---|
| Forearm linkage assembly | PLA | 75% | 4 |
| Upper arm linkage - Left/Right | PLA | 75% | 4 |
| Forearm orthotic structural insert | PLA | 75% | 4 |
| Upper arm orthotic structural insert | PLA | 75% | 4 |
| Forearm orthotics (all sizes, L/R) | TPU | 15% | 4 |
| Upper arm orthotics (all sizes, L/R) | TPU | 15% | 4 |
| Mechanical stop cover | TPU | 15% | 4 |

> **Bed adhesion tip:** If parts are not sticking to the bed well, add a brim in Bambu Studio before slicing.

---

## Print Beds

Parts are grouped into 4 print beds — 2 PLA beds and 2 TPU beds, separated by left and right arm versions. Note that the forearm linkage assembly, structural inserts, and mechanical stop covers are universal (identical for both arms) but are included in their respective bed for convenience.

> **Support removal:** Some parts require support removal after printing. TPU support removal in particular can be a long and grueling process — budget extra time for this. Surface finish on TPU orthotics may not be perfect straight off the printer; consider splitting the orthotic print into two separate prints or sanding the surface down after printing for a cleaner finish.

---

### Bed 1 — Left Arm PLA Parts
*Forearm linkage assembly (universal) + Upper arm linkage Left + Forearm orthotic structural insert (universal) + Upper arm orthotic structural insert (universal)*

**File:** `Elbow_Exoskeleton_Left_Linkage_&_Inserts_Prints.3mf`

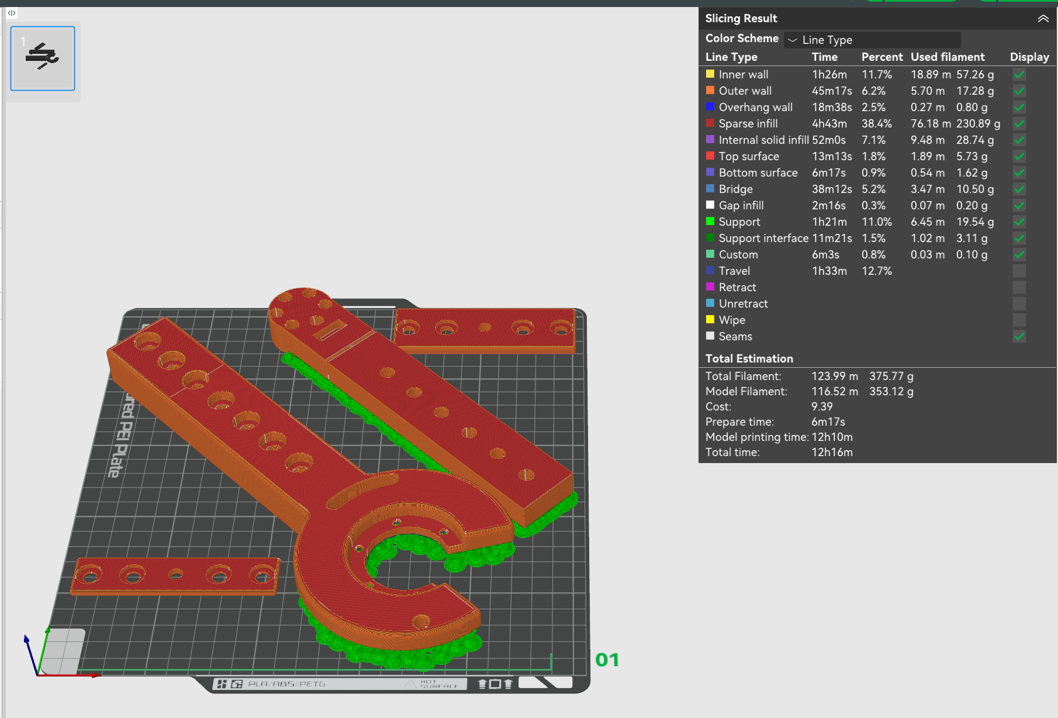
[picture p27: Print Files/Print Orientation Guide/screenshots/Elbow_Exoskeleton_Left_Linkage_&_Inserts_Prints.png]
Left PLA prints


---

### Bed 2 — Left Arm TPU Parts
*Forearm orthotic R35 Left + Upper arm orthotic R45 Left + Mechanical stop cover x2 (universal)*

**File:** `Elbow_Exoskeleton_Left_Orthotics_&_Mechanical_Stop.3mf`

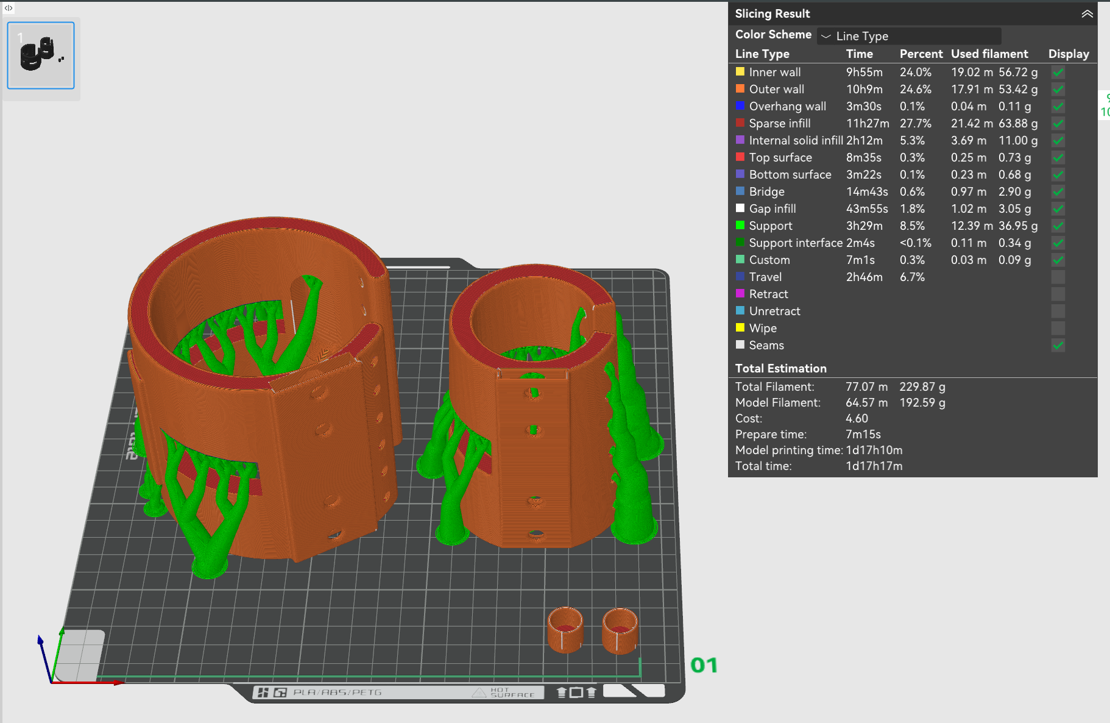
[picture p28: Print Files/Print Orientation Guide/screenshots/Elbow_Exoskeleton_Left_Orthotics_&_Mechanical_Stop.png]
Left TPU prints


---

### Bed 3 — Right Arm PLA Parts
*Forearm linkage assembly (universal) + Upper arm linkage Right + Forearm orthotic structural insert (universal) + Upper arm orthotic structural insert (universal)*

**File:** `Elbow_Exoskeleton_Right_Linkage_&_Inserts_Prints.3mf`

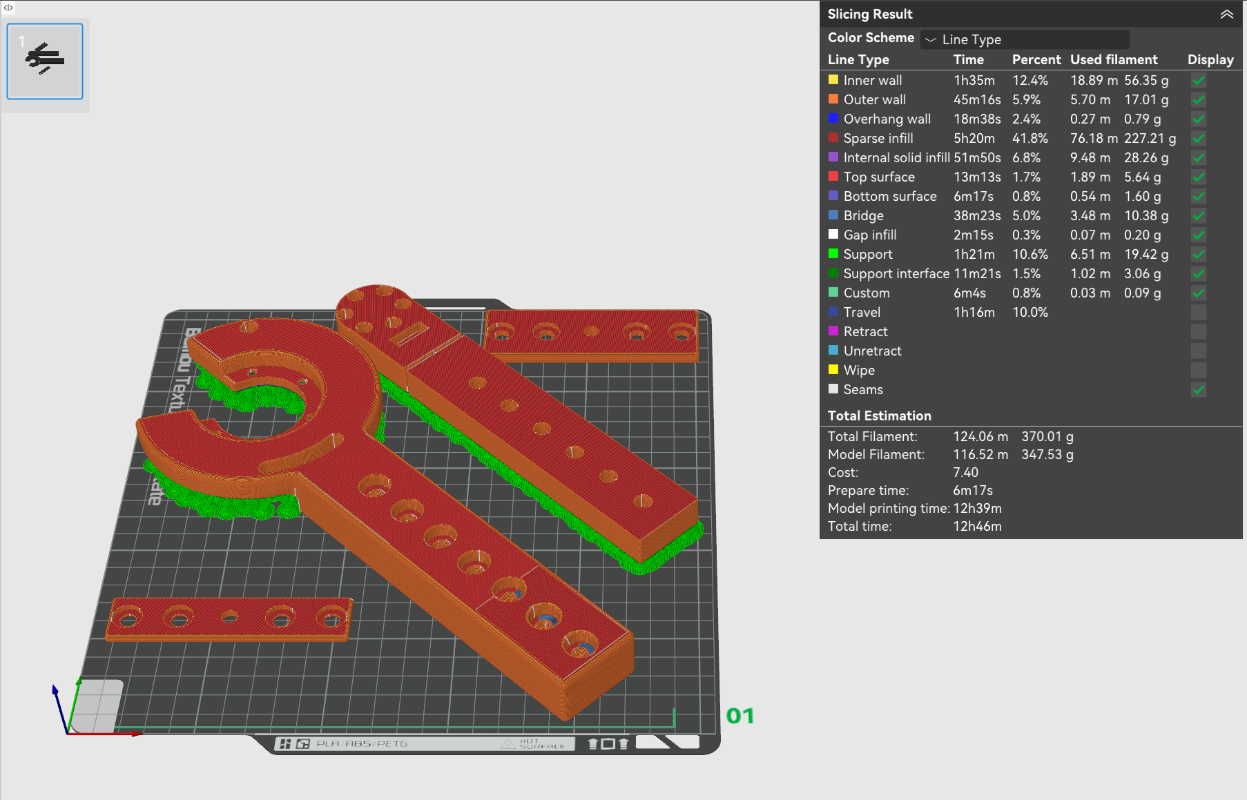
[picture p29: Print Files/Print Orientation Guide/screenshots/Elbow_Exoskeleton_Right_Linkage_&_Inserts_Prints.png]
Right PLA prints


---

### Bed 4 — Right Arm TPU Parts
*Forearm orthotic R35 Right + Upper arm orthotic R45 Right + Mechanical stop cover x2 (universal)*

**File:** `Elbow_Exoskeleton_Right_Orthotics_&_Mechanical_Stop.3mf`

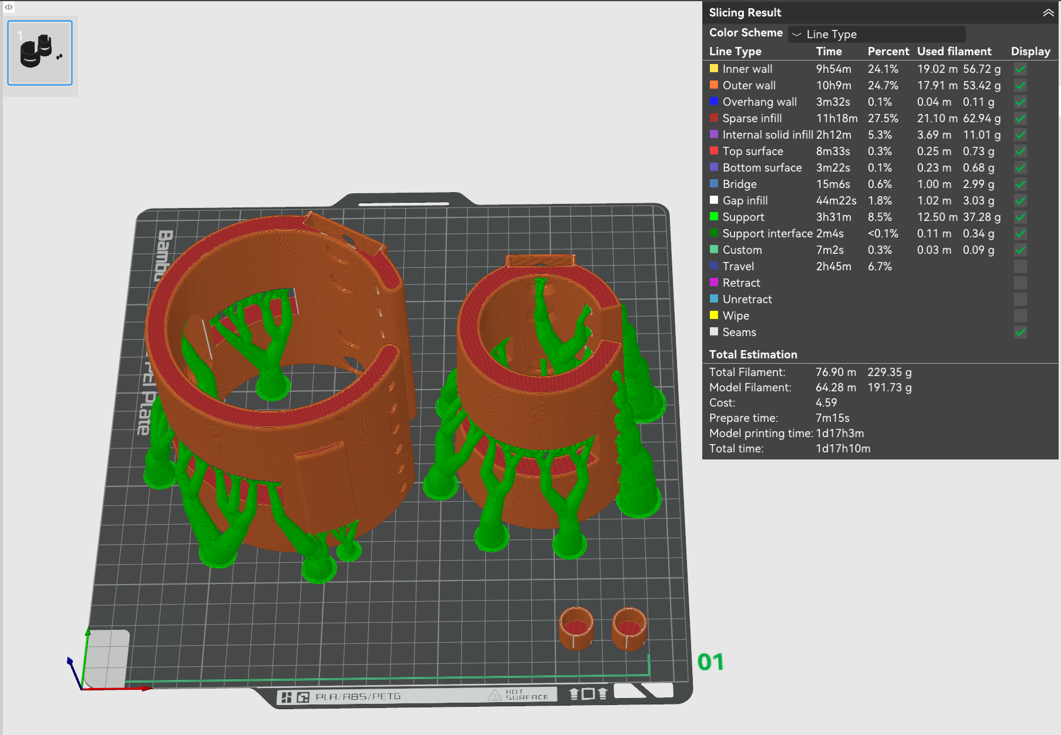
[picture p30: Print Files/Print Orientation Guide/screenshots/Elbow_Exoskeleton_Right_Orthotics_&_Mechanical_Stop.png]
Right TPU prints


---

## Forearm Linkage — Snap-Fit Interior Cross-Section

The forearm linkage assembly is a two-piece print-in-place snap-fit design. The interior geometry is specifically designed so that **no supports are generated inside the snap-fit channel or along the sliding interface**, keeping the sliding surfaces clean and functional straight off the printer.

The cross-section below shows the internal geometry in Bambu Studio Line Type view.

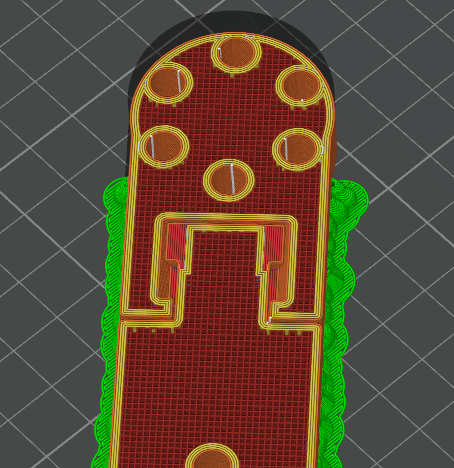
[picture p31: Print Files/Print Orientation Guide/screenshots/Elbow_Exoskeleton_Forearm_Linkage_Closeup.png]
Forearm linkage snap-fit cross-section


---

[⬆ Back to Main README](../../README.md)

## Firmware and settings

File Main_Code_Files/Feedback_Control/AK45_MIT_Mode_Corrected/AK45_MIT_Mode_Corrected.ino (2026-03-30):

// CubeMars AK45-36 MIT Mode Control with Portenta H7 on CAN1
// CORRECTED VERSION:
//   1. Proper ExitMotorMode() using 0xFD command (was missing entirely)
//   2. State is read ONLY after entering motor mode (per datasheet requirement)
//   3. Last motor position is saved to flash/EEPROM before exiting so on the
//      next power cycle the motor corrects from its saved position to abs 0-90°
//   4. Main sweep loop runs for exactly 5 seconds then exits cleanly

// Libraries Required
#include <mbed.h>
#include "Arduino_PowerManagement.h"
#include <FlashIAPBlockDevice.h>   // Portenta H7 internal flash for state persistence

// CAN Bus Setup (pins and rate)
mbed::CAN can1(PB_8, PH_13, 1000000);

// LED Pins
#define LED_RED   LEDR
#define LED_GREEN LEDG
#define LED_BLUE  LEDB

// Motor Configuration (set from cubemars app)
#define MOTOR_ID 2
const unsigned long CAN_ID = MOTOR_ID;

// -----------------------------------------------------------------------
// Value Limits — from AK-series datasheet (section 5.3, page 44)
// Position range shared by ALL AK modules: -12.5 rad to +12.5 rad
// Speed/Torque limits below match AK10-9 column in the datasheet table.
// If you are using a different module (AK60-6, AK80-6, etc.) update
// V_MAX, T_MIN, T_MAX to match that module's column in the table.
// -----------------------------------------------------------------------
#define P_MIN  -12.5f
#define P_MAX   12.5f
#define V_MIN  -50.0f
#define V_MAX   50.0f
#define KP_MIN   0.0f
#define KP_MAX 500.0f
#define KD_MIN   0.0f
#define KD_MAX   5.0f
#define T_MIN  -65.0f
#define T_MAX   65.0f

// Set Value Params
float p_in = 0.0f;
float v_in = 0.0f;
float kp_in = 5.0f;
float kd_in = 1.0f;
float t_in = 0.0f;

// Measured Value Params
float p_out = 0.0f;
float v_out = 0.0f;
float t_out = 0.0f;

// Timing
uint32_t lastSendTime    = 0;
uint32_t lastReceiveTime = 0;

// -----------------------------------------------------------------------
// Outer PD Loop Gains
// -----------------------------------------------------------------------
#define OUTER_KP 1.5f
#define OUTER_KD 0.05f

// -----------------------------------------------------------------------
// Flash persistence — we store a single float (last commanded position)
// at the very end of the internal flash.  The FlashIAPBlockDevice API lets
// us read/write a raw block without an external EEPROM.
//
// Layout (8 bytes so we stay 8-byte aligned):
//   bytes 0-3 : magic cookie  0xABCD1234  (uint32_t, big-endian)
//   bytes 4-7 : last_position as IEEE-754 float
// -----------------------------------------------------------------------
#define FLASH_MAGIC   0xABCD1234UL
#define FLASH_SIZE    8            // bytes we actually use
// Place the save block in the last sector of internal flash (2 MB device,
// last 128 kB sector starts at 0x081E0000 on STM32H747).
// Using mbed FlashIAP lets us locate it portably.
static FlashIAPBlockDevice flashDev(0x081E0000, FLASH_SIZE);

// Write the last commanded position to flash so it survives a power cycle.
void savePositionToFlash(float pos) {
  if (flashDev.init() != 0) return;

  uint8_t buf[FLASH_SIZE] = {0};
  // magic
  uint32_t magic = FLASH_MAGIC;
  memcpy(buf,     &magic, 4);
  // position
  memcpy(buf + 4, &pos,   4);

  flashDev.erase(0, FLASH_SIZE);
  flashDev.program(buf, 0, FLASH_SIZE);
  flashDev.deinit();
}

// Read the last saved position.  Returns 0.0f if no valid save exists.
float loadPositionFromFlash() {
  if (flashDev.init() != 0) return 0.0f;

  uint8_t buf[FLASH_SIZE] = {0};
  flashDev.read(buf, 0, FLASH_SIZE);
  flashDev.deinit();

  uint32_t magic;
  memcpy(&magic, buf, 4);
  if (magic != FLASH_MAGIC) return 0.0f;   // no valid previous save

  float pos;
  memcpy(&pos, buf + 4, 4);
  // Sanity-check: keep within valid range
  if (pos < P_MIN || pos > P_MAX) return 0.0f;
  return pos;
}


/*********************************************************************************************************
  CONVERSION FUNCTIONS
*********************************************************************************************************/

unsigned int float_to_uint(float x, float x_min, float x_max, int bits) {
  float span = x_max - x_min;
  float offset = x_min;
  unsigned int pgg = 0;
  if (bits == 12) pgg = (unsigned int)((x - offset) * 4095.0 / span);
  if (bits == 16) pgg = (unsigned int)((x - offset) * 65535.0 / span);
  return pgg;
}

float uint_to_float(unsigned int x_int, float x_min, float x_max, int bits) {
  float span   = x_max - x_min;
  float offset = x_min;
  float pgg = 0;
  if (bits == 12) pgg = ((float)x_int) * span / 4095.0  + offset;
  if (bits == 16) pgg = ((float)x_int) * span / 65535.0 + offset;
  return pgg;
}


/*********************************************************************************************************
  CAN COMMUNICATION SECTION
*********************************************************************************************************/

void unpack_reply(uint8_t* dat, uint8_t len) {
  if (len != 6) return;

  unsigned int id    = dat[0];
  unsigned int p_int = (dat[1] << 8) | dat[2];
  unsigned int v_int = (dat[3] << 4) | (dat[4] >> 4);
  unsigned int i_int = ((dat[4] & 0xF) << 8) | dat[5];

  p_out = uint_to_float(p_int, P_MIN, P_MAX, 16);
  v_out = uint_to_float(v_int, V_MIN, V_MAX, 12);
  t_out = uint_to_float(i_int, T_MIN, T_MAX, 12);

  lastReceiveTime = millis();

  digitalWrite(LED_BLUE, LOW);
  delayMicroseconds(100);
  digitalWrite(LED_BLUE, HIGH);
}

void pack_cmd() {
  byte buf[8];

  float p_des = constrain(p_in,  P_MIN,  P_MAX);
  float v_des = constrain(v_in,  V_MIN,  V_MAX);
  float kp    = constrain(kp_in, KP_MIN, KP_MAX);
  float kd    = constrain(kd_in, KD_MIN, KD_MAX);
  float t_ff  = constrain(t_in,  T_MIN,  T_MAX);

  unsigned int p_int  = float_to_uint(p_des, P_MIN,  P_MAX,  16);
  unsigned int v_int  = float_to_uint(v_des, V_MIN,  V_MAX,  12);
  unsigned int kp_int = float_to_uint(kp,    KP_MIN, KP_MAX, 12);
  unsigned int kd_int = float_to_uint(kd,    KD_MIN, KD_MAX, 12);
  unsigned int t_int  = float_to_uint(t_ff,  T_MIN,  T_MAX,  12);

  buf[0] = p_int >> 8;
  buf[1] = p_int & 0xFF;
  buf[2] = v_int >> 4;
  buf[3] = ((v_int & 0xF) << 4) | (kp_int >> 8);
  buf[4] = kp_int & 0xFF;
  buf[5] = kd_int >> 4;
  buf[6] = ((kd_int & 0xF) << 4) | (t_int >> 8);
  buf[7] = t_int & 0xFF;

  mbed::CANMessage msg;
  msg.id  = CAN_ID;
  msg.len = 8;
  memcpy(msg.data, buf, 8);
  can1.write(msg);
}


/*********************************************************************************************************
  MOTOR MODE SECTION
  Datasheet (section 5.3, p.43) special CAN codes:
    Enter motor control mode : { 0xFF x7, 0xFC }
    Exit  motor control mode : { 0xFF x7, 0xFD }   ← was missing before
    Set current position = 0 : { 0xFF x7, 0xFE }
  NOTE: "motor control mode must be entered before using CAN communication
         control motor!" — reading state also requires the motor to be in
         motor mode first.
*********************************************************************************************************/

bool EnterMotorMode() {
  mbed::CANMessage msg;
  msg.id  = CAN_ID;
  msg.len = 8;
  msg.data[0] = 0xFF; msg.data[1] = 0xFF; msg.data[2] = 0xFF; msg.data[3] = 0xFF;
  msg.data[4] = 0xFF; msg.data[5] = 0xFF; msg.data[6] = 0xFF; msg.data[7] = 0xFC;

  if (!can1.write(msg)) return false;

  // Send a few commands and wait for the first valid reply
  for (int i = 0; i < 5; i++) {
    pack_cmd();
    delay(10);

    mbed::CANMessage msgIn;
    if (can1.read(msgIn, 0)) {
      if (msgIn.id == CAN_ID && msgIn.len == 6) {
        unpack_reply(msgIn.data, msgIn.len);
        digitalWrite(LED_GREEN, LOW);
        return true;
      }
    }
  }
  return false;
}

// -----------------------------------------------------------------------
// ExitMotorMode — sends 0xFD as required by the datasheet.
// Also saves the last commanded position to flash BEFORE releasing control
// so the next power cycle can use it for the correction move.
// -----------------------------------------------------------------------
void ExitMotorMode(float lastCmdPos) {
  // 1. Save state while we still know what it is
  savePositionToFlash(lastCmdPos);

  // 2. Send Exit command (0xFD)
  mbed::CANMessage msg;
  msg.id  = CAN_ID;
  msg.len = 8;
  msg.data[0] = 0xFF; msg.data[1] = 0xFF; msg.data[2] = 0xFF; msg.data[3] = 0xFF;
  msg.data[4] = 0xFF; msg.data[5] = 0xFF; msg.data[6] = 0xFF; msg.data[7] = 0xFD;

  can1.write(msg);
  delay(50);  // give the driver board time to acknowledge

  digitalWrite(LED_GREEN, HIGH);  // green off = no longer in motor mode
}

void Zero() {
  mbed::CANMessage msg;
  msg.id  = CAN_ID;
  msg.len = 8;
  msg.data[0] = 0xFF; msg.data[1] = 0xFF; msg.data[2] = 0xFF; msg.data[3] = 0xFF;
  msg.data[4] = 0xFF; msg.data[5] = 0xFF; msg.data[6] = 0xFF; msg.data[7] = 0xFE;

  can1.write(msg);
  for (int i = 0; i < 5; i++) { delay(10); pack_cmd(); }
}


/*********************************************************************************************************
  moveTo — sends a position command with an outer PD correction pass.
  Returns the actual commanded position (after correction clamp) so the
  caller can track the last sent value.
*********************************************************************************************************/
float moveTo(float target_pos, uint32_t dwell_ms) {
  p_in = target_pos;

  pack_cmd();
  delay(5);

  mbed::CANMessage msgIn;
  if (can1.read(msgIn, 0)) {
    if (msgIn.id == CAN_ID && msgIn.len == 6) {
      unpack_reply(msgIn.data, msgIn.len);
    }
  }

  // Outer PD correction
  float pos_error = target_pos - p_out;
  float vel_error = 0.0f - v_out;
  float correction = constrain((OUTER_KP * pos_error) + (OUTER_KD * vel_error), -0.5f, 0.5f);
  float corrected_pos = constrain(target_pos + correction, P_MIN, P_MAX);

  p_in = corrected_pos;
  pack_cmd();
  p_in = target_pos;  // restore clean target for next call

  if (dwell_ms > 10) delay(dwell_ms - 10);

  return corrected_pos;
}


/*********************************************************************************************************
  MAIN FUNCTION SECTION
*********************************************************************************************************/

Board board;

// Track the last position we commanded so ExitMotorMode can save it.
float g_lastCmdPos = 0.0f;

// Target sweep range in radians:  0 rad (0°) → π/2 rad (90°)
#define SWEEP_MIN_RAD  0.0f
#define SWEEP_MAX_RAD  1.5708f   // π/2

// Total run time for the sweep loop (ms)
#define LOOP_DURATION_MS  5000UL


void setup() {
  board.begin();
  board.setExternalVoltage(3.3);

  pinMode(LED_RED,   OUTPUT); digitalWrite(LED_RED,   HIGH);
  pinMode(LED_GREEN, OUTPUT); digitalWrite(LED_GREEN, HIGH);
  pinMode(LED_BLUE,  OUTPUT); digitalWrite(LED_BLUE,  HIGH);

  can1.mode(mbed::CAN::Mode::Normal);
  delay(1000);

  // -----------------------------------------------------------------------
  // STEP 1 — Enter motor mode.
  // Per datasheet: state cannot be read until we are in motor control mode.
  // -----------------------------------------------------------------------
  p_in = 0.0f;
  bool entered = EnterMotorMode();

  if (!entered) {
    // Flash red to signal failure; spin forever
    while (true) {
      digitalWrite(LED_RED, LOW);  delay(200);
      digitalWrite(LED_RED, HIGH); delay(200);
    }
  }

  // -----------------------------------------------------------------------
  // STEP 2 — Read the saved position from the previous power cycle (if any)
  //          and correct to it before starting the sweep.
  //          This ensures a smooth start rather than a sudden jump.
  //
  //          We dwell for 500 ms to let the motor reach the saved position
  //          before we begin the 0→90° sweep.
  // -----------------------------------------------------------------------
  float savedPos = loadPositionFromFlash();
  if (savedPos != 0.0f) {
    // Move to the previously saved position first to avoid a jerk
    g_lastCmdPos = moveTo(savedPos, 500);
    delay(300);
  }

  // -----------------------------------------------------------------------
  // STEP 3 — Go to absolute 0 rad before the timed sweep begins.
  // -----------------------------------------------------------------------
  g_lastCmdPos = moveTo(SWEEP_MIN_RAD, 1000);
  delay(500);

  lastSendTime    = millis();
  lastReceiveTime = millis();

  digitalWrite(LED_GREEN, LOW);
  digitalWrite(LED_BLUE,  LOW);
  digitalWrite(LED_RED,   LOW);
  delay(200);
}


void loop() {
  // -----------------------------------------------------------------------
  // Timed sweep: run for exactly LOOP_DURATION_MS (5 seconds), then exit
  // motor mode cleanly, saving state, and halt.
  // -----------------------------------------------------------------------
  uint32_t loopStart = millis();

  while ((millis() - loopStart) < LOOP_DURATION_MS) {

    // Sweep forward 0 → π/2 rad
    for (float pos = SWEEP_MIN_RAD; pos <= SWEEP_MAX_RAD; pos += 0.005f) {
      if ((millis() - loopStart) >= LOOP_DURATION_MS) goto done_sweep;
      g_lastCmdPos = moveTo(pos, 20);
    }

    // Sweep back π/2 → 0 rad
    for (float pos = SWEEP_MAX_RAD; pos >= SWEEP_MIN_RAD; pos -= 0.005f) {
      if ((millis() - loopStart) >= LOOP_DURATION_MS) goto done_sweep;
      g_lastCmdPos = moveTo(pos, 20);
    }
  }

  done_sweep:

  // -----------------------------------------------------------------------
  // STEP 4 — Exit motor mode correctly (0xFD) and save the last position.
  //
  // ExitMotorMode() calls savePositionToFlash() FIRST (while the value is
  // still valid), then sends the 0xFD CAN frame.
  // On the next power cycle, setup() will load this position and move to it
  // before starting the sweep, giving continuity across resets.
  // -----------------------------------------------------------------------
  ExitMotorMode(g_lastCmdPos);

  // Signal completion: solid blue
  digitalWrite(LED_BLUE, LOW);
  digitalWrite(LED_GREEN, HIGH);
  digitalWrite(LED_RED,   HIGH);

  // Halt — do not re-enter loop()
  while (true) { delay(1000); }
}


/*********************************************************************************************************
  END FILE
  -------------------------------------------------------------------------
  CHANGE SUMMARY vs original:
  1. ExitMotorMode(float lastCmdPos) added — sends 0xFD per datasheet §5.3
     and calls savePositionToFlash() BEFORE releasing the motor.
  2. EnterMotorMode() is now called BEFORE any attempt to read motor state.
     The datasheet states: "motor control mode must be entered before using
     CAN communication control motor" — this applies to state reads too.
  3. Flash persistence (savePositionToFlash / loadPositionFromFlash) stores
     the last commanded position in the Portenta H7's internal flash using
     FlashIAPBlockDevice.  On each power cycle setup() loads this value and
     moves the motor to it before transitioning to the 0→90° sweep.
  4. Main sweep loop is now bounded by LOOP_DURATION_MS (5 000 ms).  A
     goto exits any inner for-loop the moment the 5-second window closes,
     then ExitMotorMode is called unconditionally.
  5. Sweep range changed from 0–1.57 rad (fine for 90°) — now named
     constants SWEEP_MIN_RAD / SWEEP_MAX_RAD make it easy to adjust.
*********************************************************************************************************/

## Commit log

2026-05-02 Revise README for SolidWorks file organization
    Updated the README to reflect the new organization of SolidWorks files into left and right assembly folders, including notes on shared parts and specific components.
2026-05-02 Move CAD files to a new CAD directory
    Reorganize CAD files into a dedicated CAD directory structure.
2026-05-02 Correct file paths for CAD and STL directories
    Updated paths in README for CAD and STL files.
2026-05-02 Create CAD
2026-05-02 Create STL files
2026-05-02 Improve README formatting and links for CAD/STL files
    Updated links and formatting for CAD and STL files sections in README.
2026-05-03 Create Print Orientation Guide
2026-05-03 Enhance STL printing guide with bed setups and .3mf files
    Updated the printing guide to include bed setups and added details about Bambu Studio .3mf files for the Bambu Lab P1S.
2026-05-03 Add print orientation guide for elbow exoskeleton
    This document provides a comprehensive print guide for the elbow exoskeleton, detailing print settings, bed configurations, and tips for successful printing.
2026-05-03 Enhance README with assembly and usage instructions
    Added detailed assembly and donning/doffing instructions for the orthotic device.
